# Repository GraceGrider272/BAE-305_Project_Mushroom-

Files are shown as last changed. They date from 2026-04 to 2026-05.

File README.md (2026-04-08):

# BAE-305_Project_Mushroom-

## Final Objectives:

User capability 1: Users can select media ratios. [Time Required – 5]

User capability 2: The user can observe the system automatically dispense the selected
ratios of media. [Time Required – 5]

User capability 3: The user can start the mixing process with a control mechanism. [Time
Required – 3]

User capability 4: Users can easily disassemble key components for cleaning. [Time
Required – 3]

User capability 5: The user will be alerted to an empty hopper by an indicator. [Time
Required – 3]

## Design Alternatives:

**Design Alternative 1:**
- Build a mixer that calculates ratios based on weight balance.

Justification 1:
- This option fulfills the project description by providing an alternative method for
ratio calculation and sensing.

**Design Alternative 2:**
- Build a media mixer controlled by an app.

Justification 2:
- This design choice meets the criteria and enables the project to be remotely
controlled rather than requiring manual control operations.

**Design Alternative 3:**
- The volume is measured by a time-of-flight laser sensor in the hoppers.

Justification 3:
- This still meets the criteria because the area of the hoppers does not change,
thereby allowing proper measurement of the media.

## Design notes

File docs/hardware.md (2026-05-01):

# Hardware

## Hardware Overview

This section describes the hardware components used in the small-scale mushroom media mixer prototype, as well as how they are integrated into the overall system. The hardware was selected based on cost, availability, and compatibility with the project constraints, with an emphasis on simplicity and reliability for small-scale applications.

## Main Components

The prototype system consists of the following primary hardware components:

* Microcontroller: Used to control system operations, including valve timing, motor control, and user inputs.

* Hoppers (Material Storage): Containers used to hold separate media types (e.g., soy hulls and wood pellets) prior to dispensing.

* Dispensing Mechanism (Valves/Gates): Electronically controlled gates or valves regulate the flow of material from each hopper into the mixing chamber.

* User Input Controls: Computer screen menu allows the user to start/stop the system and select mixing settings.
  
* Indicator System: The computer screen will print an alert message that notifies the user when a hopper is empty or when the system is active.
  
* Power Supply: 5V required, can easily be plugged into a computer's USB port.

### Optional / Future Components (Full-Scale System)
The prototype does not yet include all features of a full-scale system. The following components are planned for future integration:

* Water Delivery System: A pressure-regulated water source for hydrating media during mixing.
  
* Different Media Handling: Adjustable calibration settings for different media types.

## System Integration

All components are connected through the microcontroller, which serves as the central control unit. The microcontroller receives user inputs, executes the programmed logic, and sends signals to actuate the dispensing mechanisms and mixing motor. The system is designed to be modular, allowing components to be easily modified or upgraded.

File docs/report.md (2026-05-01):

UK logo 

# Project Mushroom Report

## Summary

The goal of this project was to design and develop a small-scale automated media mixer to help mushroom farmers efficiently prepare growing media. Traditional manual mixing is time-consuming and inconsistent, motivating the need for a system that improves accuracy, reduces labor, and increases convenience for small-scale operations.

The proposed design incorporates multiple hoppers for storing different media types, electronically controlled valves for dispensing precise ratios, and a mixing system that combines and hydrates the media before discharging it into a growing bag. During development, the team evaluated several design approaches, including mass and volume-based measurement systems, before selecting a final configuration that allows users to choose media ratios, automatically dispense materials, and control the mixing process.

The resulting system meets key design constraints, including affordability, compact size, and safe operation, while maintaining high accuracy in media preparation. Overall, the project delivers a practical, scalable solution that improves efficiency and consistency in mushroom farming operations.

## Design Description

The automated mushroom media mixer is a compact system comprising multiple hoppers, a dispensing mechanism, a mixing chamber, and a user control interface. Each hopper holds a different media type—for example, soy hulls or wood pellets—and is connected to electronically controlled valves that regulate material flow into the system. In a full-scale, real-world application, the design would also include a water input with a pressure-regulated source to hydrate the media during mixing. For this project, however, the team implemented a small-scale prototype focused on accurate dispensing and mixing of dry materials. The overall system layout, including hopper placement, valve configuration, and mixing chamber design, is shown in Figure 1.

<figure>
Project Mushroom
  
</figure>

*Figure 1: System Schematic*

During operation, the user specifies the desired media ratios via a control interface. Once started, the system automatically dispenses the appropriate quantities of each material from the hoppers into the mixing chamber. Dispensing is governed by programmed logic that controls valve timing and sequencing to achieve the target ratios. The control logic and overall system operation are summarized in Figure 2, and the corresponding implementation is provided in [Appendix A](final_code) (Control Code). Although the current prototype does not include the hydration component, the control architecture is designed to allow water integration in a future revision without major redesign.

<figure>
Screenshot 2026-04-15 at 4 13 11 PM

</figure>

*Figure 2: Control Flow Diagram*

The mixing mechanism then blends the materials for a user-adjustable duration, tailored to the media being prepared. The mixing system design—including motor selection and gate configuration—is detailed in Figure 3. Additional system features include empty-hopper indicators, safety measures such as enclosed moving parts, and the ability to disassemble key components for cleaning, as highlighted in [Hardware](hardware.md).

<figure>


</figure>

*Figure 3: Drawing of Mixer Assembly*

Overall, the prototype meets key functional requirements: accurate dispensing, automated operation, and user-friendly control, while remaining compact and suitable for small-scale testing and demonstration. Despite its simplified design, the model effectively captures the core functionality of a full-scale automated mixer and provides a solid foundation for future enhancements, including hydration integration and additional sensing capabilities. The files for each part are included in the parts folder BAE-305_Project_Mushroom/docs/Parts.

## Testing Descriptions 

Testing of the small-scale mushroom media mixer prototype focused on evaluating system functionality, material flow behavior, and the effectiveness of the dispensing mechanism across different operating conditions. Rather than prioritizing precise quantitative accuracy, testing emphasized ensuring that the system could reliably dispense materials without clogging and achieve visually consistent ratios.

Several materials were evaluated for suitability in the prototype. Initial testing used oatmeal; however, it proved too fine and dusty, causing inconsistent flow and excessive particulate buildup within the system. The team then tested larger cereal-based materials, including Fruit Loops and Cheerios. While these materials reduced dust-related issues, their size caused them to become lodged in the gate mechanism during closure, preventing the gates from fully sealing and disrupting controlled dispensing.

To address these issues, plastic beads were selected as the final test material. These beads were non-dusty, uniform in size, and small enough to pass through the system without becoming trapped in the gate mechanism. This allowed the gates to open and close fully and ensured consistent material flow throughout testing.

During operation, both hoppers ran simultaneously, with gate timing adjusted to approximate different dispensing ratios. The primary ratios evaluated were 1:1 (50/50), 2:3, and 3:2. These ratios were achieved by varying the duration each gate remained open rather than by direct measurement of mass or volume.

Testing was conducted iteratively, with repeated system operation to assess performance and identify issues. Rather than a fixed number of trials, the team continued testing until the system operated reliably without clogging or interruption. No formal calibration procedures were performed; however, gate timing was adjusted as needed to improve consistency in material dispensing.

System performance was evaluated based on the gates' ability to open and close without obstruction, the consistency of material flow from each hopper, and the overall functionality of the mixing process. These procedures provide a practical and repeatable approach to assessing prototype performance under realistic operating conditions.

## Design Decision Discussion

Several design alternatives were evaluated for the automated mushroom media mixer, with a focus on methods for measuring and dispensing media. The primary options considered were: (1) a weight-based system, (2) a time-based volumetric system, and (3) a time-of-flight sensor–based volume measurement system. Each option was analyzed for accuracy, cost, system complexity, and compatibility with the project’s constraints.

A weight-based system offered the highest potential accuracy because it directly measures the mass of dispensed material. However, implementing this approach would require load cells, signal conditioning, and more advanced programming, significantly increasing both system complexity and cost. Given the project’s goal of developing a compact, affordable prototype for small-scale use, this option was not practical within the available resources and time constraints.

The time-of-flight sensor approach was also considered as a non-contact method for monitoring material levels. While this method could provide additional feedback on hopper contents, it introduced potential reliability issues due to dust, irregular material surfaces, and sensor interference. Additionally, the integration complexity made it less suitable for a simple prototype system.

The final design used a time-based volumetric dispensing method, in which electronically controlled gates regulate material flow based on programmed time intervals. This decision was strongly supported by observations during testing. Early material trials revealed that flow behavior varied significantly with material size and properties, reinforcing the importance of a simple, adaptable control method. The time-based system allowed the team to easily adjust gate timing to accommodate these variations without additional hardware.

While this method does not provide the same level of precision as a weight-based system, it proved effective for achieving approximate ratios in a small-scale prototype. It also minimized mechanical and electrical complexity, making the system more reliable and easier to troubleshoot. This approach aligned well with the project’s goals of affordability, simplicity, and functional performance.

Overall, the selected design reflects a deliberate balance between accuracy and practicality. The system successfully meets the needs of a small-scale prototype while maintaining flexibility for future improvements. If higher precision is required in future iterations, the current design can be expanded to incorporate weight-based sensing or additional feedback systems without requiring a complete redesign.

## Test Result Discussion

The testing results demonstrate that the small-scale mushroom media mixer prototype reliably dispenses and mixes materials using a time-based volumetric control system. Rather than emphasizing precise quantitative accuracy, testing focused on consistent system operation and uninterrupted material flow. The final selection of plastic beads as the test material was critical to reliable performance, as earlier materials such as oatmeal and cereal products caused issues, including dust buildup and gate obstruction.

The system performed best when material properties were consistent and compatible with the gate design. Once an appropriate material was selected, both hoppers operated simultaneously without clogging, and the gates opened and closed as intended. Adjusting gate timing allowed the system to approximate ratios such as 1:1, 2:3, and 3:2, demonstrating that the control approach is flexible and functional for small-scale applications.

However, several limitations were identified during testing. The time-based dispensing method is inherently sensitive to variations in material flow characteristics, so different media types may produce different results even with identical timing settings. This was observed during early testing, where differences in particle size and shape led to inconsistent flow and mechanical interference. Additionally, because the system does not directly measure mass or volume, the exact accuracy of the dispensed ratios cannot be quantified. This limits the system's precision compared to more advanced approaches such as weight-based measurement.

The current prototype also lacks the water-hydration component found in a full-scale system, limiting its ability to fully replicate real-world mushroom media preparation. Despite this, the prototype successfully demonstrates the core functionality of automated dispensing and mixing, providing a proof of concept for future development.

Overall, the results indicate that the system is effective as a small-scale, functional prototype. It achieves consistent operation, avoids major mechanical issues when appropriate materials are used, and demonstrates the feasibility of a low-cost, automated mixing solution. Future improvements could focus on increasing accuracy through sensing methods, expanding material compatibility, and integrating hydration to more closely match real-world applications.

## Testing Results 

Testing of the mushroom media mixer prototype demonstrated that the system operated consistently and reliably when appropriate materials were used. Initial trials with oatmeal yielded poor performance due to excessive dust and fine particle size, which caused inconsistent flow and buildup within the system. Subsequent testing with larger cereal materials, including Fruit Loops and Cheerios, reduced dust-related issues but introduced mechanical interference, as the materials became lodged in the gate mechanism and prevented complete closure.

Final testing used plastic beads, which provided the most consistent and reliable results. The beads flowed smoothly through both hoppers without clogging or obstruction, allowing the gates to open and close fully as intended. Under these conditions, the system ran continuously without interruption, and both hoppers dispensed material simultaneously in a controlled manner.

Different dispensing ratios, including 1:1 (50/50), 2:3, and 3:2, were approximated by adjusting the gate open times for each hopper. While the system did not directly measure the mass or volume of the dispensed materials, visual observation indicated that the ratios were reasonably consistent across repeated runs once the gate timing was set. Minor variation was observed due to natural differences in bead flow, but overall system performance remained stable.

The mixing mechanism also performed effectively, producing a visibly uniform mixture within the selected mixing time. No significant separation or clumping was observed when using plastic beads, indicating that the mixing design and motor configuration were appropriate for the selected material.

Additional system features functioned as expected during testing. The gates operated reliably without jamming when using the final material, and the system maintained stable operation throughout repeated use. Overall, the results confirm that the prototype can achieve its primary goal of automated dispensing and mixing consistently and under controlled conditions.

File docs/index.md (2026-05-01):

# Online Design File

ChatGPT Image Apr 15, 2026 at 04_30_02 PM

## Contents
- [Report](report.md)
- [Hardware](hardware.md)
- [Software](software.md)
- [Appendix A](final_code.md)

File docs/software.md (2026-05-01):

# Software

## Software Overview

This section describes the control logic, code structure, and implementation used in the small-scale mushroom media mixer prototype. The software is responsible for automating the dispensing and mixing process based on user input while ensuring reliable and repeatable system operation.

### Control System Architecture
The system is controlled using a microcontroller (e.g., Arduino Uno), which acts as the central processing unit. The microcontroller receives user input, executes programmed logic, and sends output signals to control the dispensing mechanisms, mixing motor, and indicator system.

The control system follows a simple sequence:

1. User inputs desired settings (ratio, start command)
2. System uses sensors to check if the hoppers need a refill
3. System initiates dispensing sequence
4. Materials are released from hoppers based on timing logic
5. Mixing process begins for a set duration
6. System stops and indicates completion

A visual representation of this logic is shown in Figure 1 (Control Flow Diagram).

### Control Logic

The system operates using a time-based control approach to regulate material dispensing. Each hopper is assigned a specific activation time based on the desired ratio. The microcontroller activates each dispensing mechanism for a calculated duration to achieve the target proportions.

The general control logic includes:
* Reading user input (through menu screen)
* Converting desired ratios into timing values
* Activating dispensing outputs (gates)
* Running the mixing motor for a set time
* Monitoring system status (e.g., hopper empty indicators)

This approach allows for a simple and cost-effective implementation while maintaining acceptable accuracy for small-scale applications.

## Code Implementation

The system code is written in a microcontroller-compatible language (e.g., Arduino C/C++). The program is structured into the following main sections:

* Initialization (Setup Function): Configures input/output pins and initializes system state.
* Main Loop: Continuously checks for user input and executes the control sequence.
* Dispensing Functions: Controls timing and activation of hopper outputs.
* Indicator Functions: Handles alert notifications for system status.

The full code implementation is provided in Appendix A or linked through the project repository.

## Future Improvements

While the current software meets the needs of the prototype, several improvements can be made in future iterations:
* Closed-loop control instead of time-based operation
* Mobile or app-based interface for remote control
* Adjustable calibration settings for different media types

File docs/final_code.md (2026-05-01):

```cpp
#include <Wire.h>           // Include I2C communication library for sensors
#include <Servo.h>          // Include the standard Arduino Servo control library
#include <VL53L0X.h>        // Include the library for the VL53L0X Time-of-Flight sensor

// ===================== SENSOR SETUP =====================
#define LOX1_ADDRESS 0x30   // Define a unique I2C address for the first sensor
#define LOX2_ADDRESS 0x31   // Define a unique I2C address for the second sensor
#define SHT_LOX1 7          // Define the shutdown (XSHUT) pin for sensor 1
#define SHT_LOX2 6          // Define the shutdown (XSHUT) pin for sensor 2

VL53L0X sensor1;            // Create an object instance for the first distance sensor
VL53L0X sensor2;            // Create an object instance for the second distance sensor

// ===================== SERVO SETUP =====================
Servo servo1;               // Create a servo object to control the first motor
Servo servo2;               // Create a servo object to control the second motor
#define SERVO1_PIN 9        // Assign digital pin 9 to the first servo
#define SERVO2_PIN 10       // Assign digital pin 10 to the second servo

const uint8_t closedAngle = 0;   // Set the default resting/closed angle to 0 degrees
const uint8_t activeAngle = 45;  // Set the base operational/shaking angle to 45 degrees

// ===================== STATE MANAGEMENT =====================
int jitterCount1 = 0;       // Variable to store how many shakes Servo 1 should perform
int jitterCount2 = 0;       // Variable to store how many shakes Servo 2 should perform

bool servosActive = false;   // Flag to track if the servos are currently in motion
bool modeSelected = false;   // Flag to track if the user has picked a menu option

int lastValidDistance1 = -1; // Stores the most recent successful reading from sensor 1
int lastValidDistance2 = -1; // Stores the most recent successful reading from sensor 2

// ===================== SETUP =====================
void setup() {
  Serial.begin(57600);       // Initialize serial communication at 57600 baud rate
  Wire.begin();              // Initialize the I2C bus

  pinMode(SHT_LOX1, OUTPUT); // Set sensor 1 shutdown pin as an output
  pinMode(SHT_LOX2, OUTPUT); // Set sensor 2 shutdown pin as an output

  digitalWrite(SHT_LOX1, LOW); // Pull sensor 1 shutdown pin low to reset
  digitalWrite(SHT_LOX2, LOW); // Pull sensor 2 shutdown pin low to reset
  delay(10);                   // Short pause to ensure sensors have powered down

  initSensors();               // Call helper function to assign addresses and boot sensors

  servo1.attach(SERVO1_PIN);   // Connect the first servo object to its physical pin
  servo2.attach(SERVO2_PIN);   // Connect the second servo object to its physical pin
  
  servo1.write(closedAngle);   // Move servo 1 to the starting closed position
  servo2.write(closedAngle);   // Move servo 2 to the starting closed position

  displayMenu();               // Print the control options to the Serial Monitor
}

// ===================== LOOP =====================
void loop() {
  handleMenu();                // Check for user input from the Serial Monitor

  if (modeSelected && !servosActive) { // Run sensor logic only if armed and not currently moving
    bool valid1 = false;       // Local flag to track if sensor 1 read correctly this loop
    bool valid2 = false;       // Local flag to track if sensor 2 read correctly this loop

    uint16_t mm1 = sensor1.readRangeSingleMillimeters(); // Get distance reading in mm from sensor 1
    if (!sensor1.timeoutOccurred()) {                    // Check if the sensor responded in time
      lastValidDistance1 = mm1 / 10;                     // Convert mm to cm and update global variable
      valid1 = true;                                     // Mark this reading as valid
    }

    uint16_t mm2 = sensor2.readRangeSingleMillimeters(); // Get distance reading in mm from sensor 2
    if (!sensor2.timeoutOccurred()) {                    // Check if the sensor responded in time
      lastValidDistance2 = mm2 / 10;                     // Convert mm to cm and update global variable
      valid2 = true;                                     // Mark this reading as valid
    }

    Serial.print(F("S1: "));                             // Label for sensor 1 output
    if (valid1) { Serial.print(lastValidDistance1); Serial.print(F(" cm")); } // Print cm if valid
    else { Serial.print(F("invalid")); }                 // Print error message if reading failed

    Serial.print(F(" | S2: "));                          // Separator for sensor 2 output
    if (valid2) { Serial.print(lastValidDistance2); Serial.println(F(" cm")); } // Print cm if valid
    else { Serial.println(F("invalid")); }               // Print error message if reading failed

    if (lastValidDistance1 != -1 && lastValidDistance2 != -1) { // If both sensors have data
      if (lastValidDistance1 >= 6 || lastValidDistance2 >= 6) {  // Check if bin is empty (distance > 6cm)
        Serial.println(F(">>> REFILL NOW"));                     // Alert user to refill
      } else {                                                   // If something is detected close by
        Serial.println(F("Triggered!"));                         // Confirm the system is acting
        runJitterCycle();                                        // Execute the servo shaking routine
      }
    }
    
    delay(300); // Wait 300ms before the next sensor poll to prevent spamming
  }
}

// ===================== SERVO CONTROL =====================

void runJitterCycle() {
  servosActive = true;                         // Set flag to prevent loop logic interference
  int maxShakes = max(jitterCount1, jitterCount2); // Determine which servo needs more shakes
  
  Serial.println(F("Dispensing..."));          // Log status to serial
  
  for (int i = 0; i < maxShakes; i++) {        // Loop through the shake count
    // 1. Move Up (Higher Jitter)
    if (i < jitterCount1) servo1.write(activeAngle + 10); // Adjust servo 1 upward
    if (i < jitterCount2) servo2.write(activeAngle + 10); // Adjust servo 2 upward
    delay(100);                                           // Wait for movement
    
    // 2. Move Down (Lower Jitter)
    if (i < jitterCount1) servo1.write(activeAngle - 5);  // Adjust servo 1 downward
    if (i < jitterCount2) servo2.write(activeAngle - 5);  // Adjust servo 2 downward
    delay(100);                                           // Wait for movement

    // FIX: Snap a servo closed the INSTANT its specific count is reached
    if (i == (jitterCount1 - 1)) {             // Check if servo 1 finished its shakes
      servo1.write(closedAngle);               // Immediately return servo 1 to closed position
    }
    if (i == (jitterCount2 - 1)) {             // Check if servo 2 finished its shakes
      servo2.write(closedAngle);               // Immediately return servo 2 to closed position
    }
  }

  Serial.println(F("Cycle complete. Returning to menu.")); // Notify user cycle is over
  
  servosActive = false;  // Allow sensors to be read again
  modeSelected = false;  // Reset selection to require new user input
  displayMenu();         // Show menu again for the next operation
}

void shakeGatesManual() {
  Serial.println(F(">>> MANUAL SHAKE..."));    // Log manual override status
  for (int i = 0; i < 2; i++) {                // Run exactly two shake cycles
    servo1.write(activeAngle + 10);            // Move both servos up
    servo2.write(activeAngle + 10);
    delay(100);                                // Wait
    servo1.write(activeAngle - 5);             // Move both servos down
    servo2.write(activeAngle - 5);
    delay(100);                                // Wait
  }
  servo1.write(closedAngle);                   // Force servo 1 to closed state
  servo2.write(closedAngle);                   // Force servo 2 to closed state
  Serial.println(F("Manual shake complete.")); // Log completion
  displayMenu();                               // Return to main menu
}

// ===================== HELPERS =====================

void initSensors() {
  Serial.println(F("Initializing sensors...")); // Start of initialization sequence
  digitalWrite(SHT_LOX1, HIGH);                 // Power on the first sensor
  delay(10);                                    // Wait for boot-up
  sensor1.init();                               // Initialize internal sensor settings
  sensor1.setAddress(LOX1_ADDRESS);             // Assign the custom I2C address 0x30
  sensor1.setMeasurementTimingBudget(200000);   // Set high accuracy timing (200ms)

  digitalWrite(SHT_LOX2, HIGH);                 // Power on the second sensor
  delay(10);                                    // Wait for boot-up
  sensor2.init();                               // Initialize internal sensor settings
  sensor2.setAddress(LOX2_ADDRESS);             // Assign the custom I2C address 0x31
  sensor2.setMeasurementTimingBudget(200000);   // Set high accuracy timing (200ms)
  Serial.println(F("Sensors OK"));              // Confirm setup success
}

void displayMenu() {
  Serial.println();                             // Print empty line for readability
  Serial.println(F("--- JITTER DISPENSER MENU ---")); // Header
  Serial.println(F("1: S1 x5 | S2 x5"));        // Option 1 description
  Serial.println(F("2: S1 x3 | S2 x5"));        // Option 2 description
  Serial.println(F("3: S1 x5 | S2 x3"));        // Option 3 description
  Serial.println(F("4: STUCK - Shake Gates x2")); // Option 4 description
}

void handleMenu() {
  if (!modeSelected && Serial.available()) {    // If waiting for input and data is in buffer
    char c = Serial.read();                     // Read the incoming character
    if (c == '1') { jitterCount1 = 5; jitterCount2 = 5; modeSelected = true; }      // Set mode 1
    else if (c == '2') { jitterCount1 = 3; jitterCount2 = 5; modeSelected = true; } // Set mode 2
    else if (c == '3') { jitterCount1 = 5; jitterCount2 = 3; modeSelected = true; } // Set mode 3
    else if (c == '4') { shakeGatesManual(); return; }                              // Run manual shake
    else { return; }                                                                // Ignore other keys

    Serial.println(F("Mode selected. System armed.")); // Confirm selection to user
  }
}
```

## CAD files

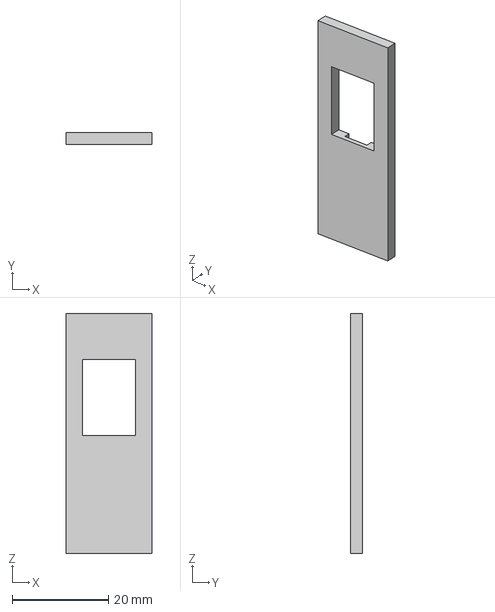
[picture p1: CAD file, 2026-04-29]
docs/Parts/TOF Sensor Holder.step
18.0 x 2.40 x 50.0 mm

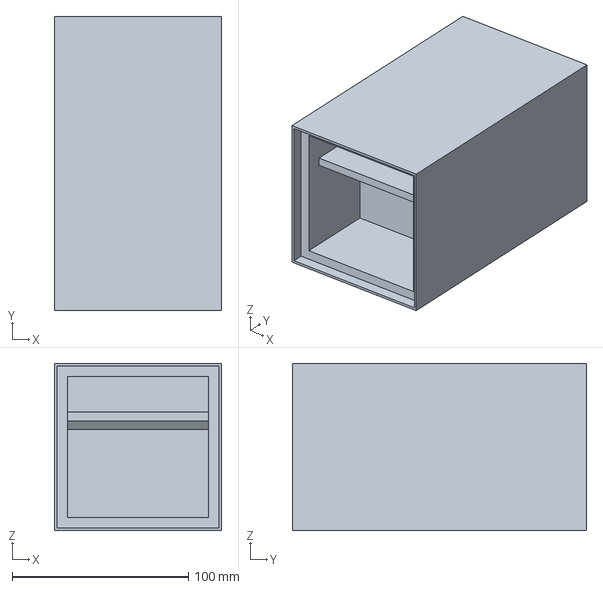
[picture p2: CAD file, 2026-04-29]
docs/Parts/External1.step
94.9 x 167.0 x 94.9 mm

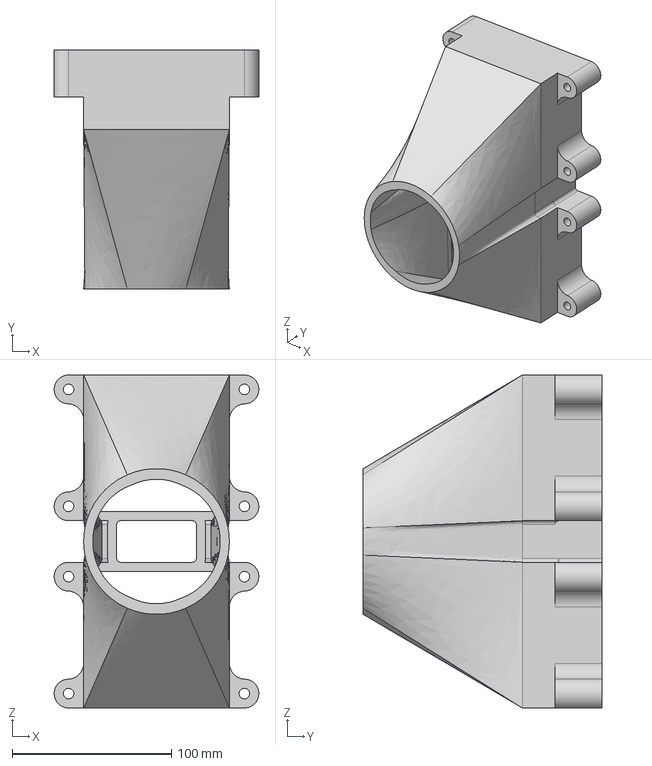
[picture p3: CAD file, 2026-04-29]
docs/Parts/Feeder.step
128.5 x 150.0 x 209.1 mm

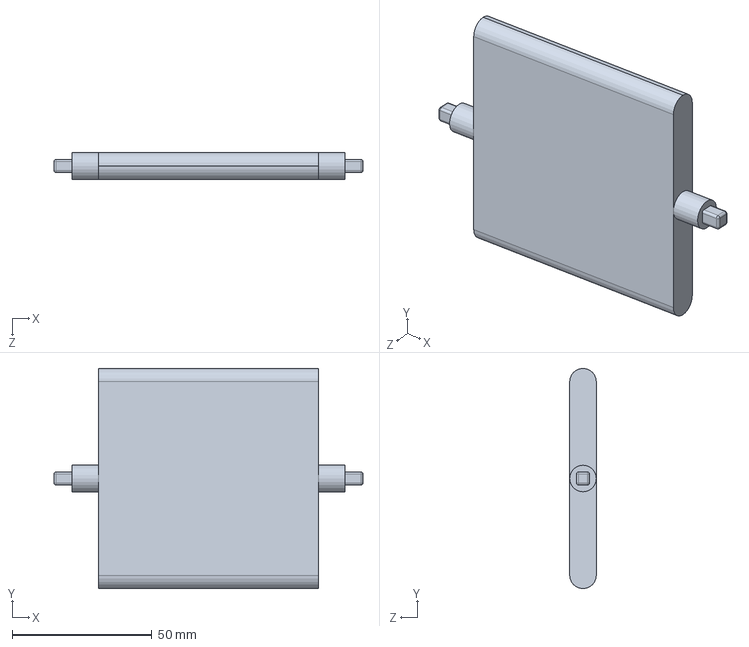
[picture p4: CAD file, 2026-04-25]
docs/Parts/Vent Flap 2.SLDPRT
110.5 x 78.7 x 9.53 mm

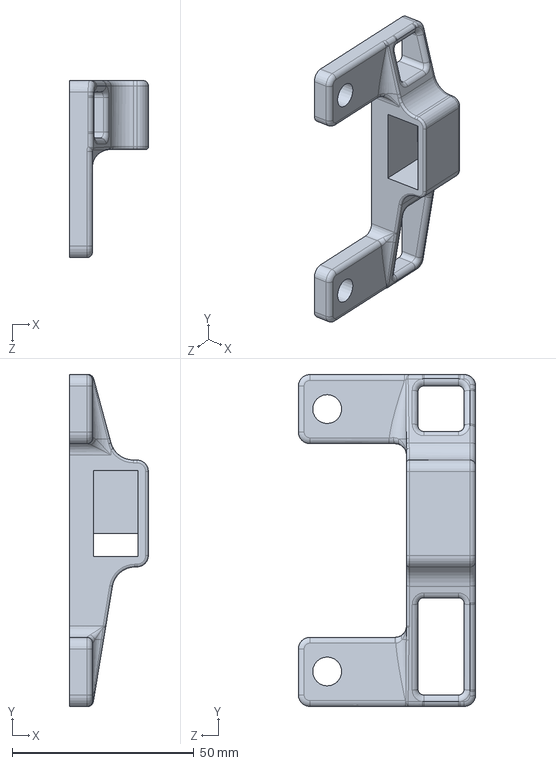
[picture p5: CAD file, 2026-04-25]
docs/Parts/Servo Mount.SLDPRT
21.7 x 91.4 x 48.8 mm

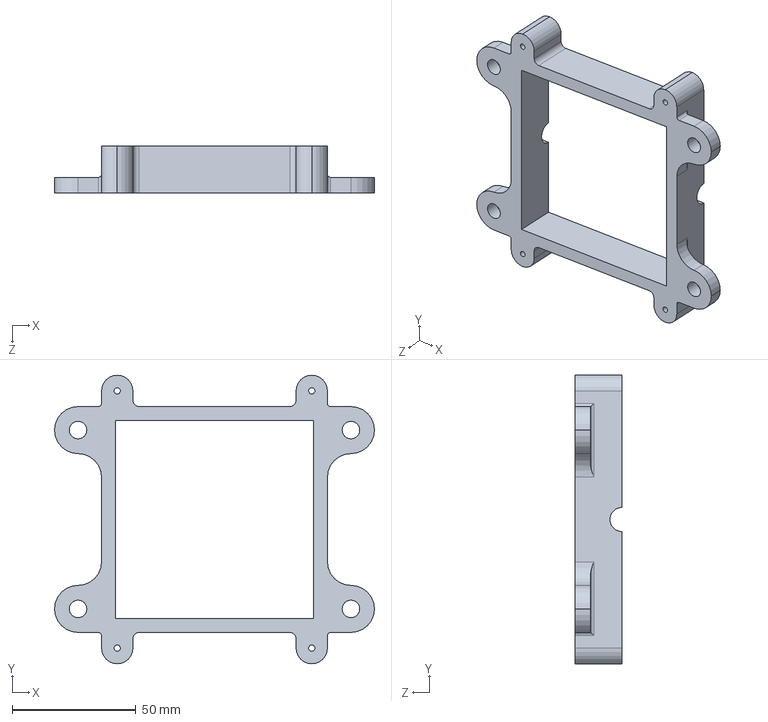
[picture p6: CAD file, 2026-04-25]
docs/Parts/Vent Mount 3.SLDPRT
129.5 x 116.8 x 19.1 mm

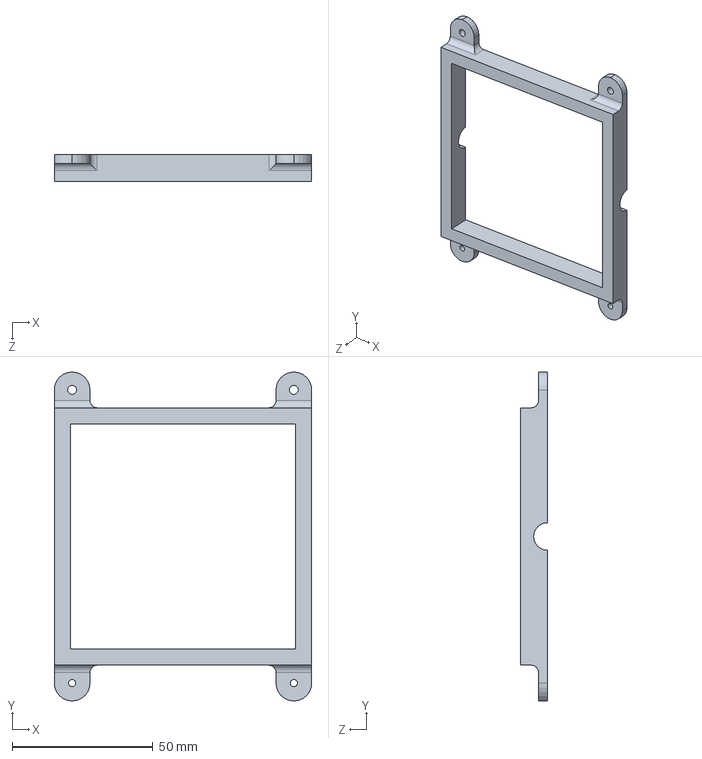
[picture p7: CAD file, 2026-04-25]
docs/Parts/Vent Mount 4.SLDPRT
91.4 x 116.8 x 9.53 mm

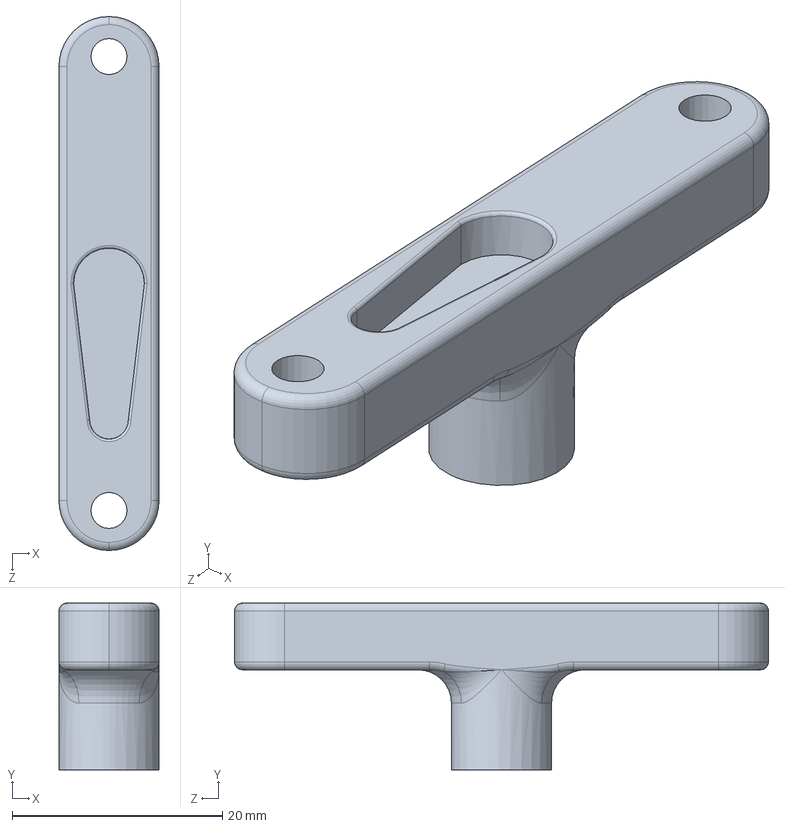
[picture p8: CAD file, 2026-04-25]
docs/Parts/Servo Attachment.SLDPRT
9.53 x 15.9 x 50.8 mm

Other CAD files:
docs/Parts/Parts/External1.step

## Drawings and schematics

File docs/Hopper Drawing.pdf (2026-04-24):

18.2 167 160 2.4 6.2

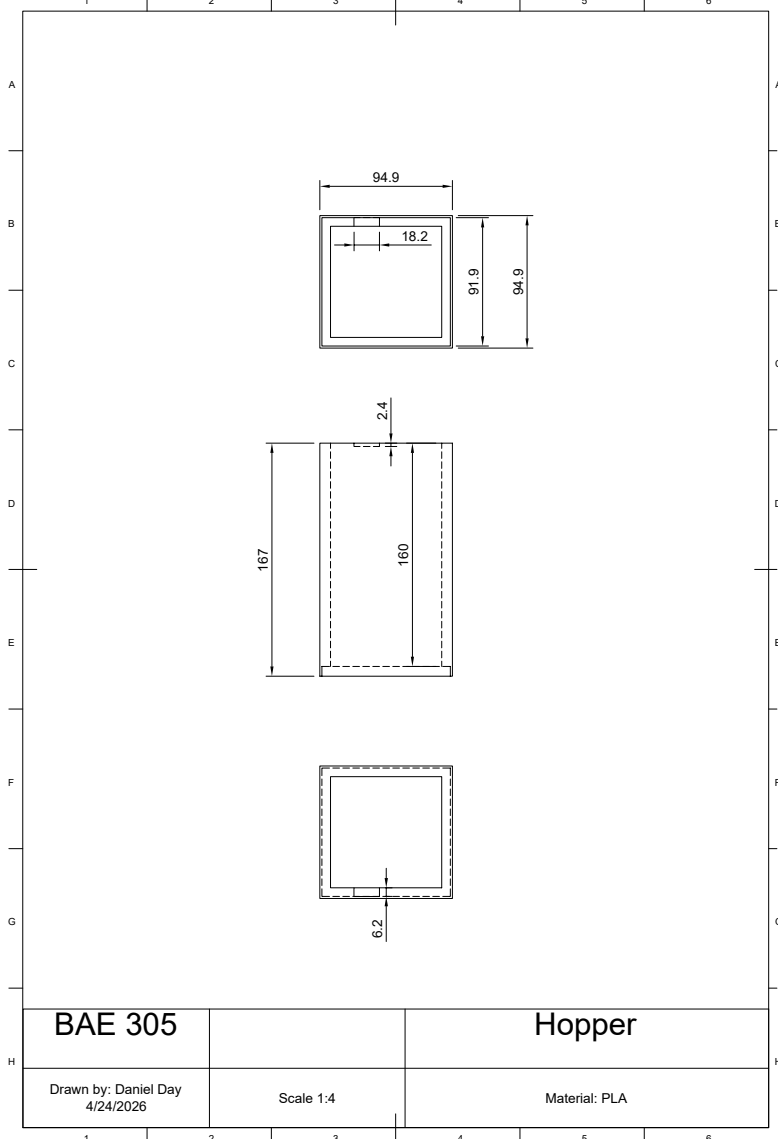
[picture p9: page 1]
Scale 1:4; Material: PLA; BAE 305; Hopper

Drawn by: Daniel Day

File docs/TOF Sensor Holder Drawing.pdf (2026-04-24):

11 2.4

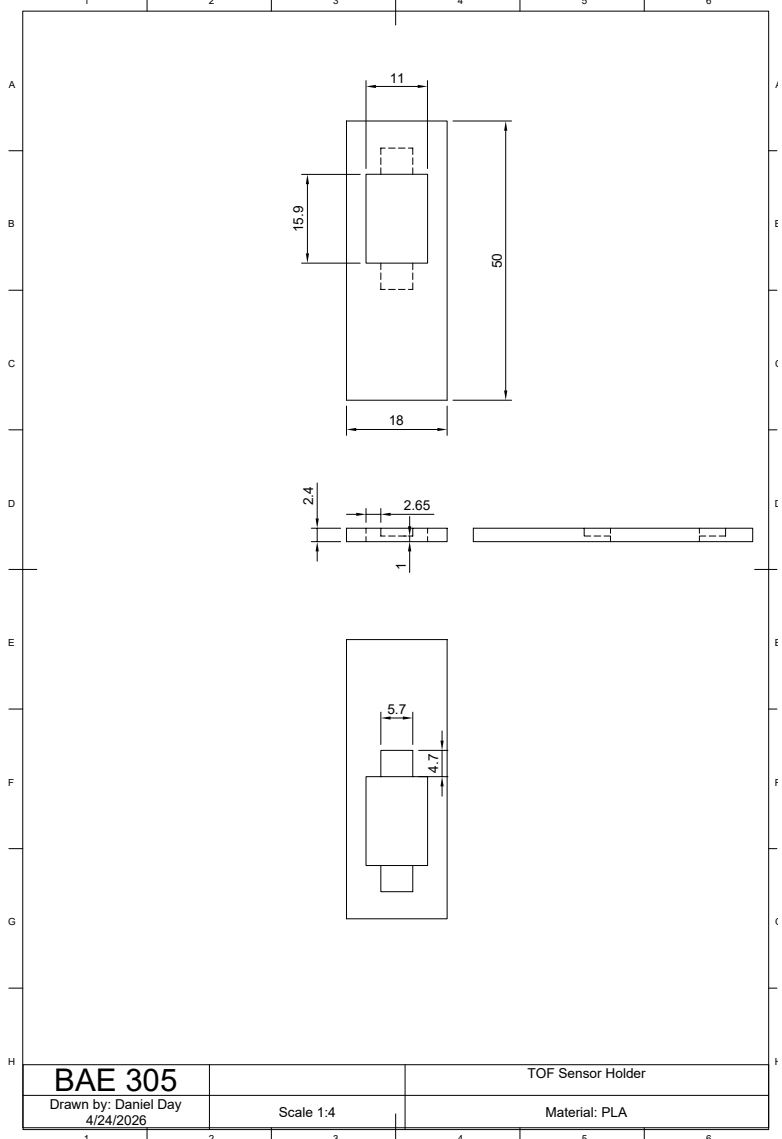
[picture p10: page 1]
Scale 1:4; Material: PLA; BAE 305; TOF Sensor Holder

Drawn by: Daniel Day

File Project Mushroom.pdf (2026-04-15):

A

1 | 2 | 3 | 4 | 5 | 6

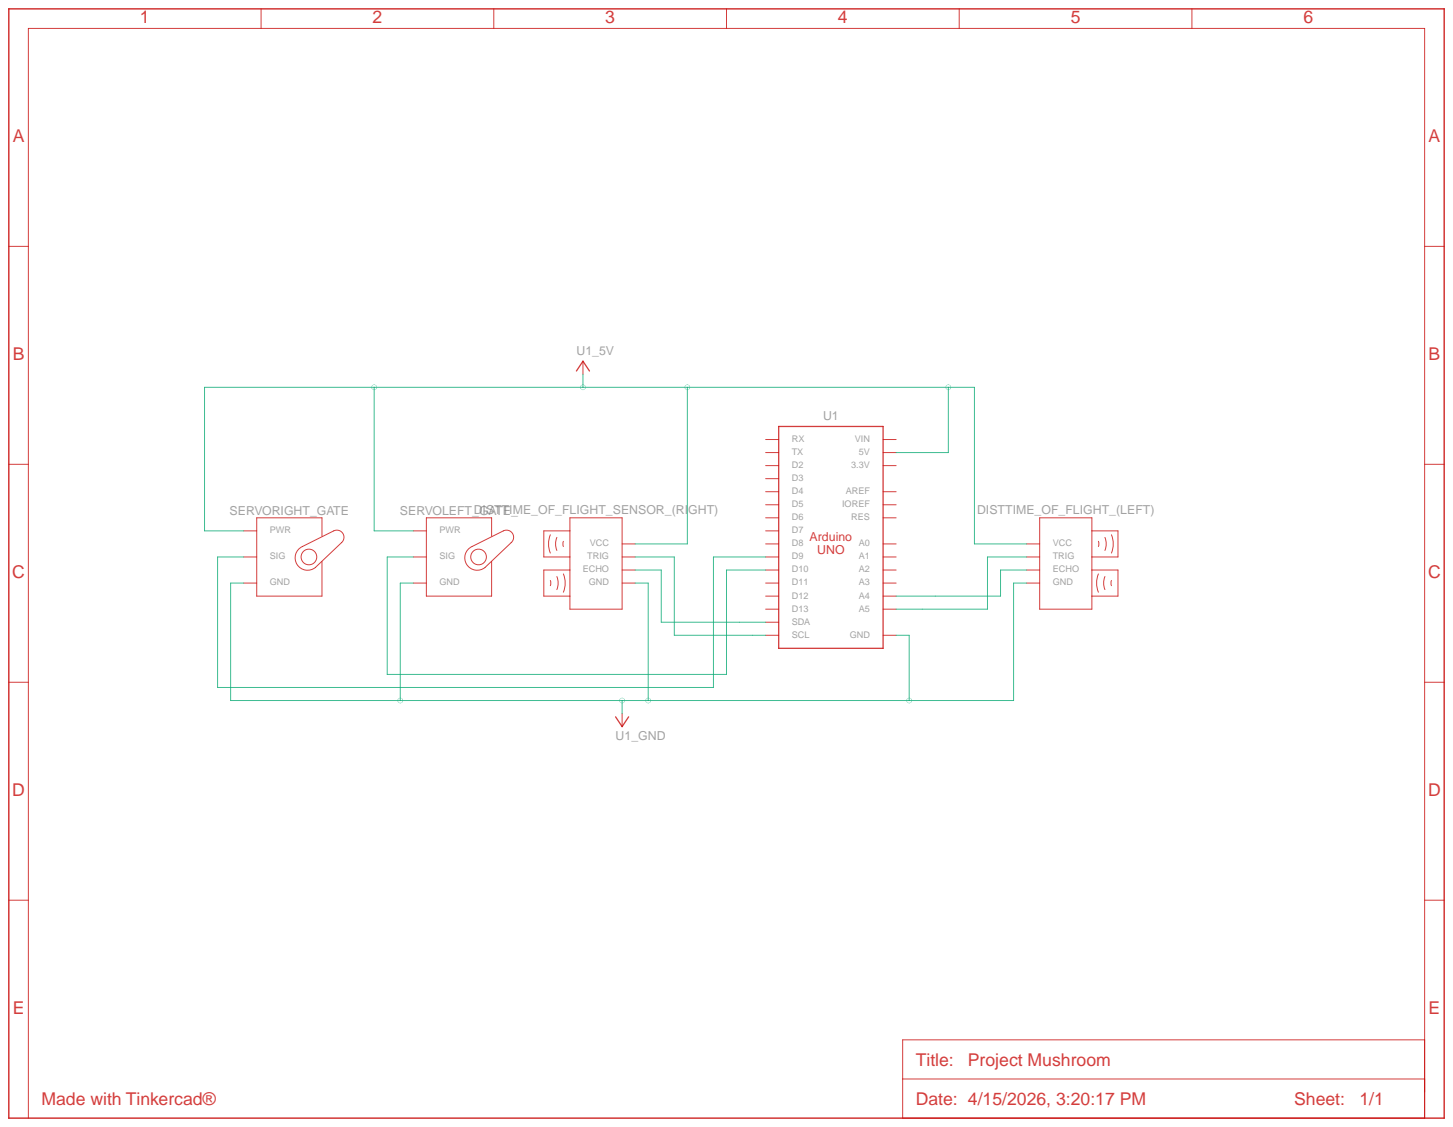
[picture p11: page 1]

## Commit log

2026-03-11 Add prototype code for servo and laser sensor control
    Implemented control for two servos based on distance measurements from two laser sensors.
2026-03-11 Commented on servo and sensor control code
2026-03-11 Implement servo control with button inputs and sensors
    This code initializes two servos and laser sensors, checks hopper levels, and controls servo rotation based on button presses.
2026-04-08 Both servos and one sensor code
2026-04-22 Add initial implementation of sensor and servo control
2026-04-22 Add complete sensor and servo control implementation
2026-04-24 add figure for assembly
2026-04-24 Add files via upload
    3D Models for in-house components
    [External1.step, Feeder.step, TOF Sensor Holder.step]
2026-04-25 Add External1.step file to Parts directory
    [External1.step]
2026-04-25 Add TOF Sensor Holder design file
    [TOF Sensor Holder.step]
2026-04-29 Added the updated assembly drawing
    Added a new image and updated the design description section to correct a typo and include additional information about the prototype's functionality and parts.
2026-04-29 Added all part design files
    [External1.step, Feeder.step, TOF Sensor Holder.step]
2026-05-01 Refactor sensor and servo initialization code
2026-05-01 Revise user input and indicator system descriptions
    Updated user input controls and indicator system descriptions to reflect changes in interface from buttons to a computer screen.
2026-05-01 Revise control sequence and improve documentation clarity
    Updated the control sequence to include sensor checks for hoppers and refined user input handling. Adjusted terminology for clarity in the control logic section.
